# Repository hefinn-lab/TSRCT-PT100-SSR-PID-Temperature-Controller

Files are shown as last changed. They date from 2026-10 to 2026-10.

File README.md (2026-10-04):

# An Open-Source Dual-Channel RTD Thermal-Control Platform for Research-Scale PEM Water Electrolysis Balance-of-Plant Integration

The **Thermal Stability Regulatory Control Tool** **(TSRCT-PCB-01)** is an Arduino Nano Every–based temperature-control board for experimental thermal management. It connects two Pt100 or Pt1000 resistance temperature detectors (RTDs) to independent **5 V digital solid-state-relay (SSR) control outputs**, with controller power and host communication through a single USB connection. External SSRs switch a separately powered heater circuit.

**Repository release: v1.1.1 | Firmware and Python tools: V1.1**

[Setup and dependencies](DEPENDENCIES.md) • [Release notes](RELEASE-NOTES.md) • [Citation](CITATION.cff) • [Licensing](LICENSE.md)

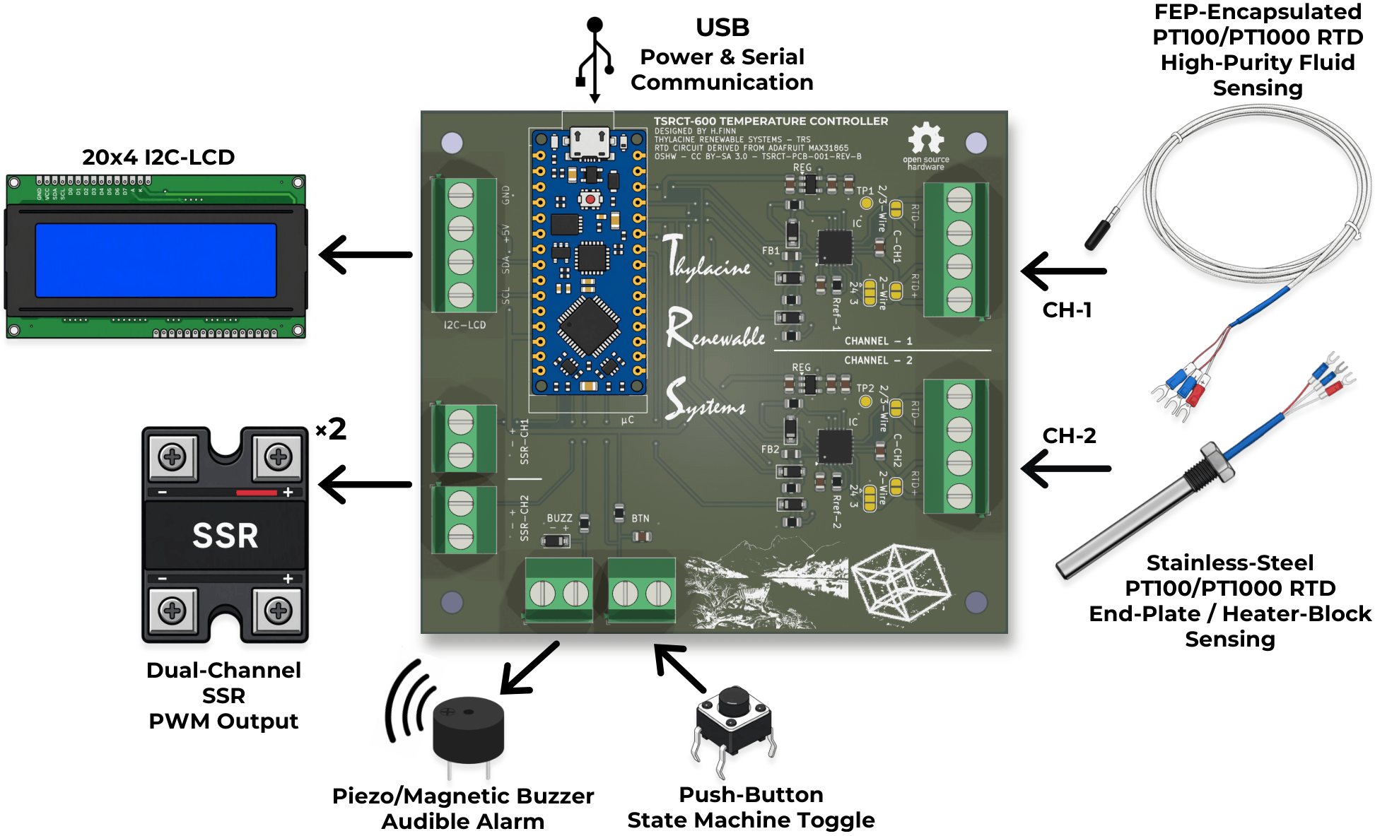
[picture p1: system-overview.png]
TSRCT-PCB-01 system overview showing dual RTD inputs, SSR outputs, USB communication and user-interface connections


The accompanying manuscript describes the circuit, analytical tuning methods, experimental results, and operating scope. The reported experiments characterise temperature control on isolated, dry electrolysis-cell end plates.

## Ordering assembled boards

Assembled boards (PCB fabrication, component sourcing, and assembly) can be ordered through PCBWay. Choose the listing that matches your sensors:

[Pt100 version](https://www.pcbway.com/project/shareproject/TSRCT_PT100_SSR_PID_Temperature_Controller_67959e58.html) | [Pt1000 version](https://www.pcbway.com/project/shareproject/TSRCT_PT1000_SSR_PID_Temperature_Controller_ba38c86e.html) | [Pt100/Pt1000 hybrid version](https://www.pcbway.com/project/shareproject/TSRCT_PT100_PT1000_SSR_PID_Temperature_Controller_0d5c73a0.html)

All three use the same PCB -- only the reference resistors and RTD input-filter capacitors differ. To use another manufacturer, the Gerber and drill files, plus a BOM and position file for each variant, are in [`Hardware/TSRCT-PCB-01-Manufacturing-Files`](Hardware/TSRCT-PCB-01-Manufacturing-Files/).

The hybrid Pt100/Pt1000 version configures channel 1 as Pt100, and channel 2 as Pt1000.

Assembled boards arrive configured for 4-wire RTDs, with the Arduino Nano Every unprogrammed -- see [RTD wiring and soldering](#rtd-wiring-and-soldering) for 2- and 3-wire use.

Disclosure: the author receives a 10% donation from PCBWay on orders placed through these listings.

## Basic functions

- Two MAX31865 RTD acquisition channels with independent temperature set points.
- Pt100 or Pt1000 operation, with matching component population and firmware settings; configurable 2-, 3-, or 4-wire connections.
- PI/PID control, manual operation, set-point ramping, and anti-windup.
- Windowed SSR actuation, with nominal 1 s control and actuation windows.
- Open-loop step-response acquisition and FOPDT-based analytical SIMC PI / iSIMC PID tuning tools.
- USB serial telemetry and companion Python logging and analysis.
- RTD fault handling, stale-measurement detection, and over-temperature alarms that disable both heater commands.
- Connections for an I²C display, push button, and audible alarm.

## Adafruit design attribution and changes

**The RTD front ends are based on the Adafruit MAX31865 breakout design by Limor Fried/Ladyada for Adafruit Industries.** The MAX31865 interface software is derived from Adafruit's Arduino library. The original projects are:

- [Adafruit MAX31865 hardware: schematics and PCB files](https://github.com/adafruit/Adafruit-MAX31865-PCB)
- [Adafruit MAX31865 Arduino library](https://github.com/adafruit/Adafruit_MAX31865)

**Hardware changes:** TSRCT-PCB-01 integrates two RTD front ends into one control PCB with the Nano Every, SSR command connections, and display, button, and alarm interfaces. The layout consolidates the measurement and control wiring while retaining configurable RTD connections. Reference resistors and input-filter capacitors are populated for the selected sensor type.

**Firmware changes:** RTD acquisition has been changed to a **non-blocking state machine**. Bias settling, conversion waiting, and readout are scheduled as separate stages so acquisition does not hold up the main loop during the sensor waiting periods. The application adds independent control loops, timer-scheduled SSR windows, analytical tuning support, fault handling, and host telemetry. The V1.1 timer implementation uses the Nano Every's ATmega4809 TCB2 peripheral; another microcontroller requires timer adaptation.

## RTD wiring and soldering

Use the Adafruit learning guide for the underlying RTD connection principles and solder-jumper configuration:

- [MAX31865 guide: overview](https://learn.adafruit.com/adafruit-max31865-rtd-pt100-amplifier/)
- [Assembly and soldering guide](https://learn.adafruit.com/adafruit-max31865-rtd-pt100-amplifier/assembly)
- [RTD wiring and configuration: 2-, 3-, and 4-wire sensors](https://learn.adafruit.com/adafruit-max31865-rtd-pt100-amplifier/rtd-wiring-config)

These instructions illustrate the Adafruit breakout. Use the **TSRCT-PCB-01 schematic and PCB labels** to identify the corresponding terminals and jumpers before soldering or cutting a trace.

| Sensor | Nominal resistance at 0 °C | Reference resistor | RTD input-filter capacitor |
| --- | ---: | ---: | ---: |
| Pt100 | 100 Ω | 430 Ω | 100 nF |
| Pt1000 | 1000 Ω | 4.3 kΩ | 10 nF |

Set the firmware's nominal RTD resistance, reference-resistor value, and wiring mode to match each populated channel. Changing from Pt100 to Pt1000 requires matching hardware and software configuration. The V1.1 default configuration uses two three-wire Pt100 sensors with 430 Ω reference resistors.

## Getting started

1. Assemble the board using its schematic and bill of materials, or order an assembled board (see above). Then make the solder jumpers and the firmware wiring mode agree with your sensors: the board's jumpers default to 4-wire, while the V1.1 firmware defaults to 3-wire. For 3-wire sensors, set the jumpers as described above; for 4-wire sensors, change `RTD_WIRE_COUNT` in the sketch.
2. Follow [DEPENDENCIES.md](DEPENDENCIES.md) to configure the Arduino Nano Every target and Arduino megaAVR Boards core, install the Python packages, and select the matching sketch/logger pair.
3. Connect the RTDs and compatible SSR control inputs, checking input-current requirements against the board's output capability. Heater power must pass through the external switching circuit, with independent thermal protection.
4. Upload the nominal-control or analytical-tuning sketch and run its companion Python logger. Before enabling heater power, confirm plausible temperature readings, correct sensor-to-heater channel pairing, and heater-off behaviour on your assembled system.

The loggers record telemetry; closing a logger does not stop heating. Use the controller's local control/abort function. Repository documentation can receive a new release version while unchanged firmware and Python tools retain V1.1.

## Attribution and licensing

Hardware design files are licensed under **CC BY-SA 3.0**. Original TSRCT software contributions are licensed under **MIT**, and Adafruit-derived code retains its upstream notices. See [LICENSE.md](LICENSE.md) for the component-specific terms and [ADAFRUIT-NOTICES.md](ADAFRUIT-NOTICES.md) for attribution. Preserve the applicable notices when redistributing or modifying the design or software.

Please acknowledge the original Adafruit projects when reusing these RTD front ends or their interface code, and refer to the accompanying manuscript for the TSRCT-PCB-01 design and experimental methods.

## Contact

Technical questions and bug reports: please open a [GitHub issue](https://github.com/hefinn-lab/TSRCT-PT100-SSR-PID-Temperature-Controller/issues). Other enquiries: Hamish Emmerson Finn, University of Tasmania, hamish.finn@utas.edu.au ([ORCID](https://orcid.org/0009-0000-0281-6255)).

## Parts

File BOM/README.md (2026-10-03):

# Reference BOM

`BOM.xlsx` is the reference bill of materials for TSRCT-PCB-01. It is intended for manual ordering and assembly: it lists Digi-Key part numbers and can be uploaded to Digi-Key's BOM tool. Quantities are for one board. The red rows are the sensor-dependent parts; order the reference resistors and channel capacitors that match each channel's sensor type (Pt100 or Pt1000).

For automated assembly (PCBA), use the files in [`Hardware/TSRCT-PCB-01-Manufacturing-Files`](../Hardware/TSRCT-PCB-01-Manufacturing-Files/) instead. That folder holds a separate BOM and position file for each population (Pt100, Pt1000, and Pt100/Pt1000), formatted for assembler upload, together with the Gerber and drill files.

Both use the same reference designators as the schematic and PCB.

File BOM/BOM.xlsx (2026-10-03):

Qty | Digi-Key Part Number | Manufacturer Part Number | Manufacturer | Customer Reference | Designation | Footprint | Notes
1 |  | ABX00033 | Arduino | uC1 | Arduino Nano Every | Module:Arduino_Nano | Nano Every (ATmega4809) required by the firmware. Same footprint as the classic Nano, which is not supported.
2 | MAX31865ATP+-ND | MAX31865ATP+ | Analog Devices | IC1, IC2 | MAX31865 | Package_DFN_QFN:TQFN-20-1EP_5x5mm_P0.65mm_EP3.1x3.1mm_ThermalVias | TQFN-20 5x5mm -- verified
2 | 576-2980-1-ND | MIC5225-3.3YM5-TR | Microchip | REG1, REG2 | MIC5225-3.3 | Package_TO_SOT_SMD:SOT-23-5 | SOT-23-5 -- verified
7 | 31-1N4148W-7-F-WCT-ND | 1N4148W-7-F-W | Diodes Inc. | D1–D7 | 1N4148 | Diode_SMD:D_SOD-123 | SOD-123 verified (NOT SOD-323). -W variant in stock
2 | 490-1054-1-ND | BLM21PG221SN1D | Murata | FB1, FB2 | Ferrite 220Ω @ 100MHz | Inductor_SMD:L_0805_2012Metric | 0805 verified
VAR. | P430DACT-ND | ERA-6AEB431V | Panasonic | Rref-1, Rref-2 (Pt100 channels) | 430Ω 0.1% thin-film | Resistor_SMD:R_0805_2012Metric | 0805 verified - Rref for PT100 channels. Populate one per PT100 channel
VAR. | P4.3KDACT-ND | ERA-6AEB432V | Panasonic | Rref-1, Rref-2 (Pt1000 channels) | 4.3kΩ 0.1% thin-film | Resistor_SMD:R_0805_2012Metric | 0805 verified - Rref for Pt1000 channels. Populate one per PT1000 channel
7 | 311-10.0KCRCT-ND | RC0805FR-0710KL | Yageo | R2, R3, R4, R6, R7, R8, R9 | 10K 1% | Resistor_SMD:R_0805_2012Metric | 0805 verified
1 | 311-220CRCT-ND | RC0805FR-07220RL | Yageo | R10 | 220Ω 1% | Resistor_SMD:R_0805_2012Metric | 0805 verified
4 | 1276-1003-1-ND | CL21B104KBCNNNC | Samsung | C1, C2, C8, C9 | 0.1uF X7R 50V | Capacitor_SMD:C_0805_2012Metric | 0805 verified. Decoupling.
VAR. | 1276-1003-1-ND | CL21B104KBCNNNC | Samsung | C-CH1, C-CH2 (Pt100 channels) | 0.1uF X7R 50V | Capacitor_SMD:C_0805_2012Metric | PT100 channel filter. Placed as C-CH1/C-CH2. Populate one per PT100 channel
4 | 1276-6454-1-ND | CL21A106KAYNNNG | Samsung | C4, C5, C11, C13 | 10uF X5R 25V | Capacitor_SMD:C_0805_2012Metric | 0805 verified. G-variant of original E-variant (out of stock); identical electrical spec.
1 | 1276-1029-1-ND | CL21B105KBFNNNE | Samsung | C6 | 1uF X7R 50V | Capacitor_SMD:C_0805_2012Metric | 0805 verified. Button debounce.
VAR. | 1276-1015-1-ND | CL21B103KBANNNC | Samsung | C-CH1, C-CH2 (Pt1000 channels) | 10nF X7R 50V | Capacitor_SMD:C_0805_2012Metric | PT1000 channel filter. Placed as C-CH1/C-CH2. Populate one per PT1000 channel
3 | 277-1265-ND | 1715747 | Phoenix Contact | J6, J7, I2C-LCD1 | Screw_Terminal_01x04 5.08mm | TerminalBlock_Phoenix:TerminalBlock_Phoenix_MKDS-1,5-4-5.08_1x04_P5.08mm_Horizontal | MKDS 1,5/4-5,08 — 4-pos 5.08mm verified
4 | 277-1263-ND | 1715721 | Phoenix Contact | SSR-CH1, SSR-CH2, BTN1, BUZZ1 | Screw_Terminal_01x02 5.08mm | TerminalBlock_Phoenix:TerminalBlock_Phoenix_MKDS-1,5-2-5.08_1x02_P5.08mm_Horizontal | MKDS 1,5/2-5,08 — 2-pos 5.08mm
 | BOM Note: All quantities are for one assembled TSRCT-PCB-001 PCB unless otherwise stated. Red rows are RTD-configuration-dependent components; populate the appropriate values for the selected PT100/PT1000 channel configuration. Reference designators match the schematic, the PCB and the assembly files in TSRCT-PCB-01-Manufacturing-Files.

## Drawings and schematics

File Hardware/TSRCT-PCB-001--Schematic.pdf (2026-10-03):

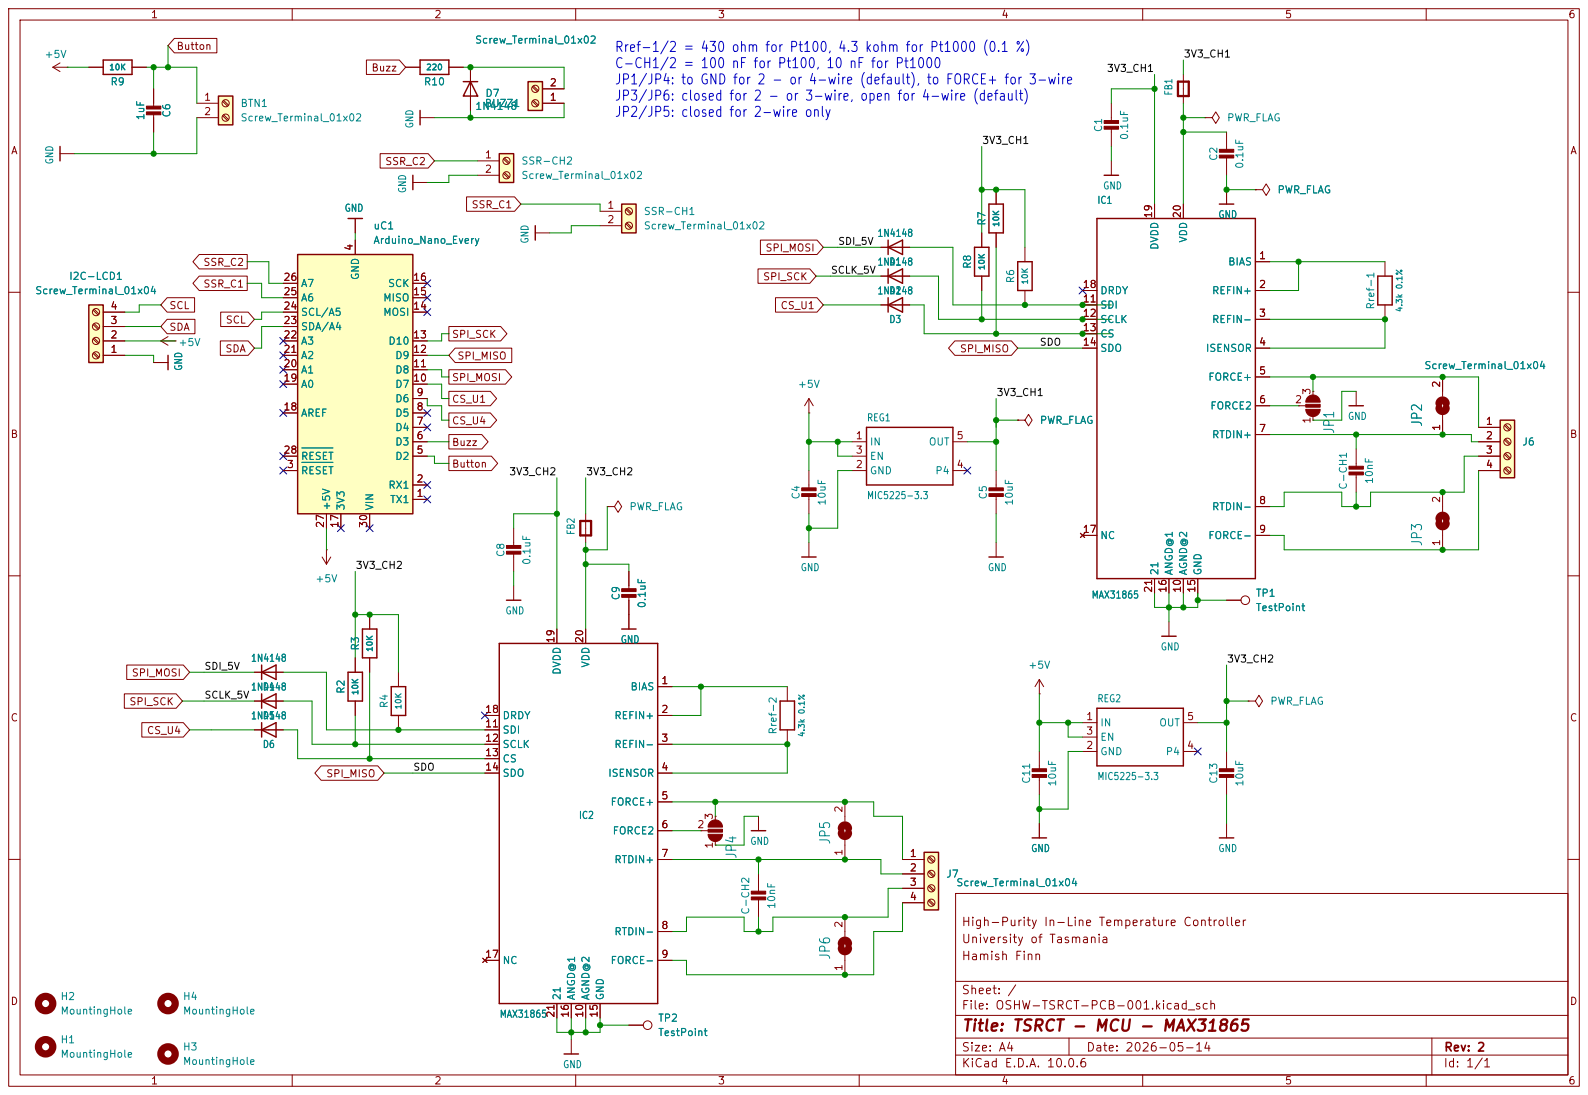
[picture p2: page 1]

C-CH1/2 = 100 nF for Pt100, 10 nF for Pt1000
JP1/JP4: to GND for 2 - or 4-wire (default), to FORCE+ for 3-wire
JP3/JP6: closed for 2 - or 3-wire, open for 4-wire (default)
JP2/JP5: closed for 2-wire only

High-Purity In-Line Temperature Controller GND GND

Sheet: /
File: OSHW-TSRCT-PCB-001.kicad_sch
Title: TSRCT - MCU - MAX31865

Size: A4 | Rev: 2
KiCad E.D.A. 10.0.6 | Id: 1/1

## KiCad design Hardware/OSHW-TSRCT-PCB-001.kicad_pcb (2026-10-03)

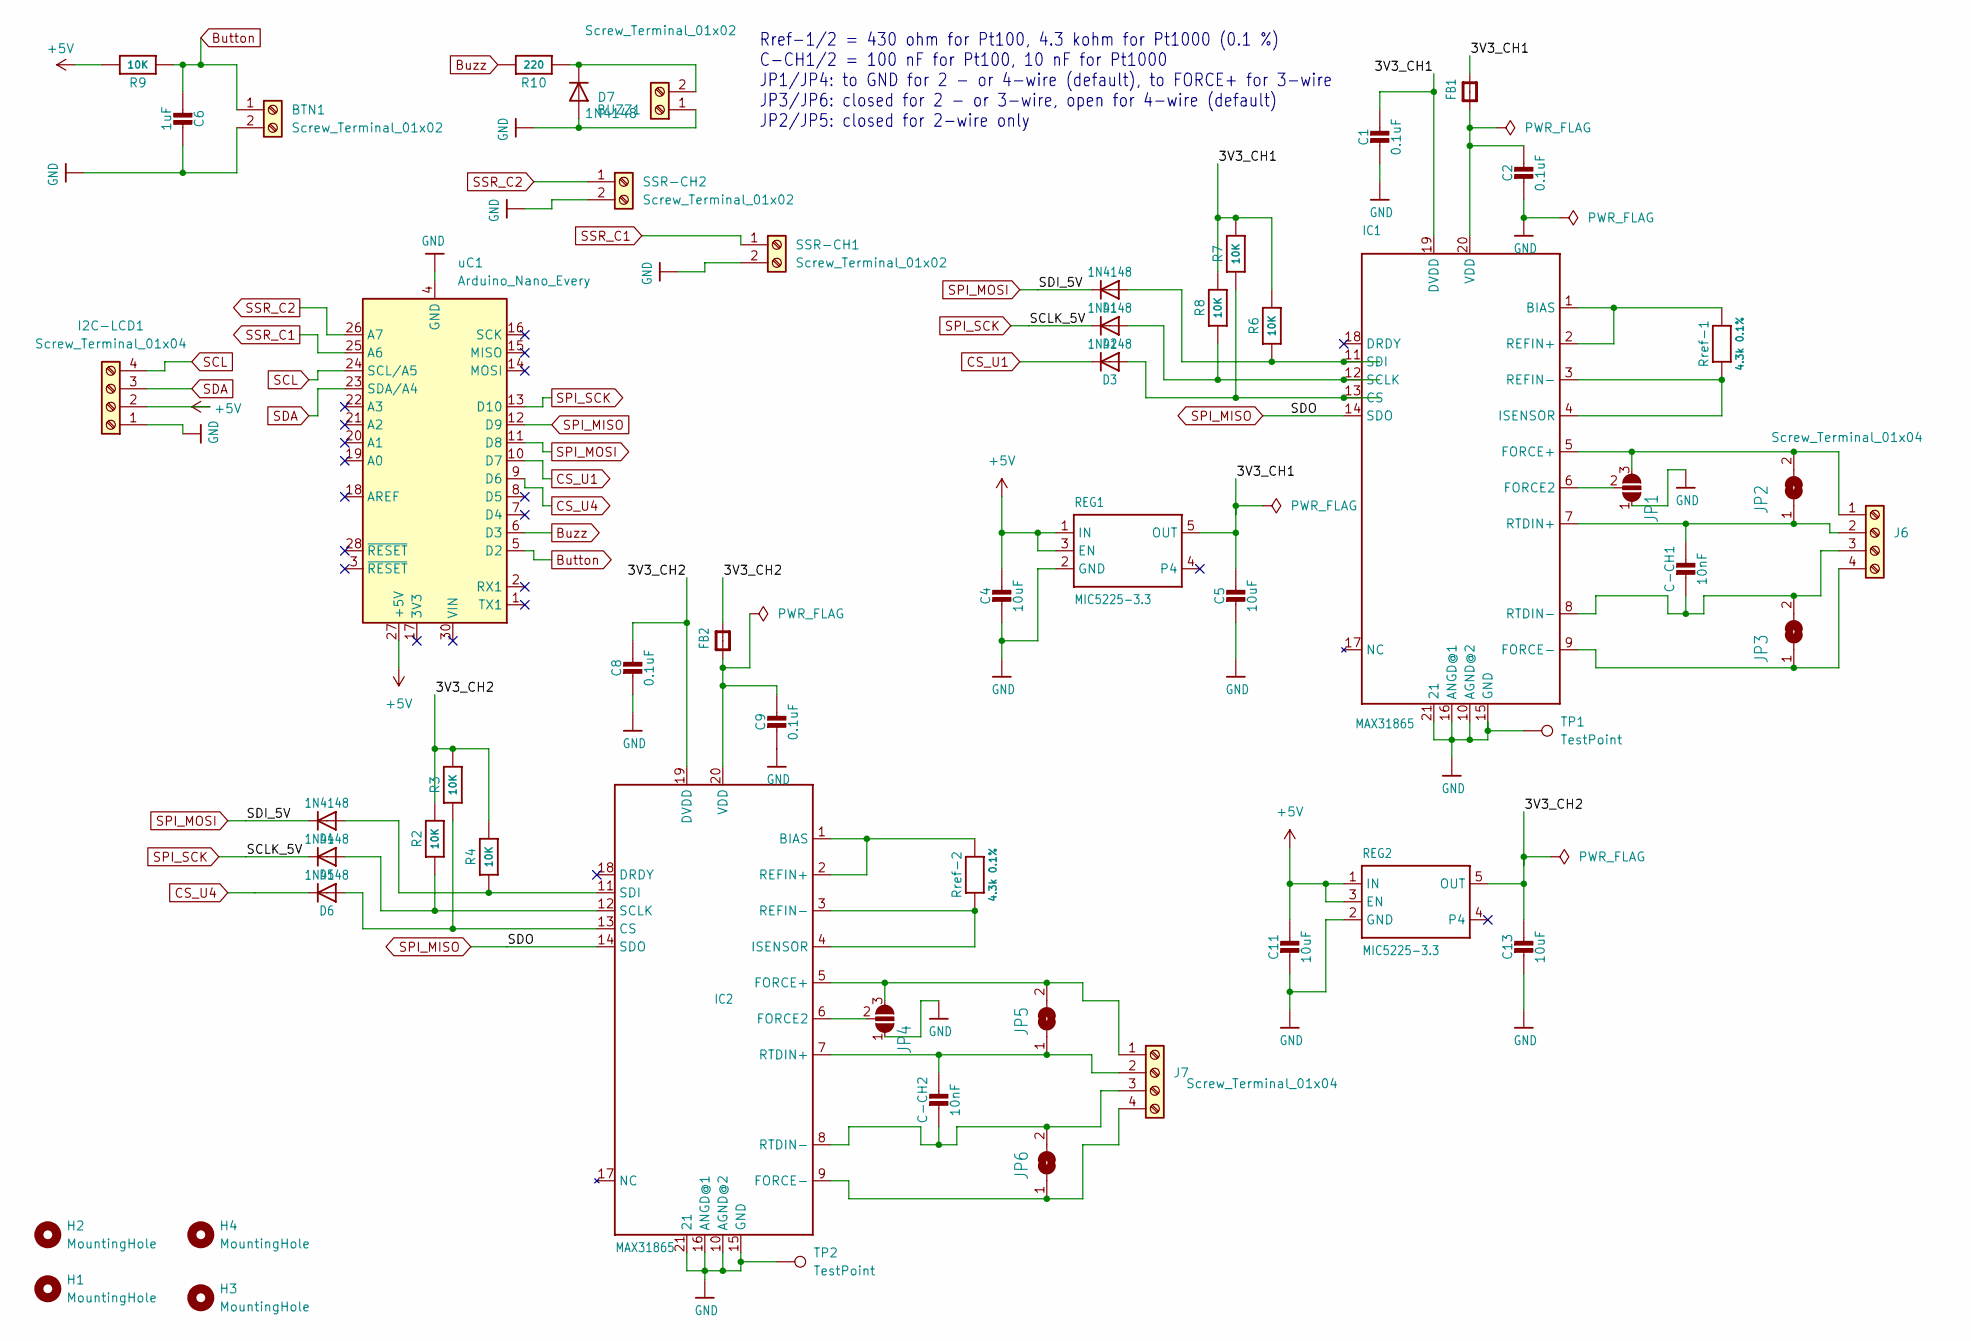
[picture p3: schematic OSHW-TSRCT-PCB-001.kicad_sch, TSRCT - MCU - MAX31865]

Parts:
BTN1: Screw_Terminal_01x02; TerminalBlock_Phoenix_MKDS-1,5-2-5.08_1x02_P5.08mm_Horizont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
BUZZ1: Screw_Terminal_01x02; TerminalBlock_Phoenix_MKDS-1,5-2-5.08_1x02_P5.08mm_Horizont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
C1, C2, C8, C9: 0.1uF; C_0805_2012Metric
C4, C5, C11, C13: 10uF; C_0805_2012Metric
C6: 1uF; C_0805_2012Metric
C-CH1, C-CH2: 10nF; C_0805_2012Metric
D1, D2, D3, D4, D5, D6, D7: 1N4148; D_SOD-123
FB1, FB2: FERRITE-0805NO; L_0805_2012Metric
H1, H2, H3, H4: MountingHole; MountingHole_3.2mm_M3
I2C-LCD1: Screw_Terminal_01x04; TerminalBlock_Phoenix_MKDS-1,5-4-5.08_1x04_P5.08mm_Horizont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
IC1, IC2: MAX31865; TQFN-20-1EP_5x5mm_P0.65mm_EP3.1x3.1mm_ThermalVias
J6, J7: Screw_Terminal_01x04; TerminalBlock_Phoenix_MKDS-1,5-4-5.08_1x04_P5.08mm_Horizont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
JP1, JP4: 24 3; SolderJumper-3_P1.3mm_Bridged12_RoundedPad1.0x1.5mm
JP2, JP5: 2-Wire; SolderJumper-2_P1.3mm_Open_RoundedPad1.0x1.5mm
JP3, JP6: 2/3-Wire; SolderJumper-2_P1.3mm_Open_RoundedPad1.0x1.5mm
R2, R3, R4, R6, R7, R8, R9: 10K; R_0805_2012Metric
R10: 220; R_0805_2012Metric
REG1, REG2: MIC5225-3.3; SOT-23-5
Rref-1, Rref-2: 4.3k 0.1%; R_0805_2012Metric
SSR-CH1, SSR-CH2: Screw_Terminal_01x02; TerminalBlock_Phoenix_MKDS-1,5-2-5.08_1x02_P5.08mm_Horizont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
TP1, TP2: TestPoint; TestPoint_Pad_D1.5mm
uC1: Arduino_Nano_Every; Arduino_Nano

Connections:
+5V: C4.1, C11.1, I2C-LCD1.2, R9.2, REG1.1 (IN), REG1.3 (EN), REG2.1 (IN), REG2.3 (EN), uC1.27 (+5V)
/3V3_CH1: C1.1, C5.1, FB1.2, IC1.19 (DVDD), R6.2, R7.2, R8.2, REG1.5 (OUT)
/3V3_CH2: C8.1, C13.1, FB2.2, IC2.19 (DVDD), R2.2, R3.2, R4.2, REG2.5 (OUT)
Button: BTN1.1, C6.2, R9.1, uC1.5 (D2)
Buzz: R10.2, uC1.6 (D3)
CS_U1: D3.1, uC1.10 (D7)
CS_U4: D6.1, uC1.9 (D6)
GND: BTN1.2, BUZZ1.1, C1.2, C2.2, C4.2, C5.2, C6.1, C8.2, C9.2, C11.2, C13.2, D7.2 (A), I2C-LCD1.1, IC1.10 (AGND@2), IC1.15 (GND), IC1.16 (ANGD@1), IC1.21, IC2.10 (AGND@2), IC2.15 (GND), IC2.16 (ANGD@1), IC2.21, JP1.1, JP4.1, REG1.2 (GND), REG2.2 (GND), SSR-CH1.2, SSR-CH2.2, TP1.1 (1_1), TP2.1 (1_1), uC1.4 (GND), uC1.29 (GND)
unnamed: BUZZ1.2, D7.1 (K), R10.1
unnamed: C2.1, FB1.1, IC1.20 (VDD)
unnamed: C9.1, FB2.1, IC2.20 (VDD)
unnamed: IC1.1 (BIAS), IC1.2 (REFIN+), Rref-1.2
unnamed: D3.2, IC1.13 (CS), R7.1
unnamed: IC1.6 (FORCE2), JP1.2
unnamed: IC1.5 (FORCE+), J6.1, JP1.3, JP2.2
unnamed: IC1.9 (FORCE-), J6.4, JP3.1
unnamed: IC1.3 (REFIN-), IC1.4 (ISENSOR), Rref-1.1
unnamed: C-CH1.1, IC1.7 (RTDIN+), J6.2, JP2.1
unnamed: C-CH1.2, IC1.8 (RTDIN-), J6.3, JP3.2
unnamed: D2.2, IC1.12 (SCLK), R8.1
unnamed: D1.2, IC1.11 (SDI), R6.1
unnamed: IC2.1 (BIAS), IC2.2 (REFIN+), Rref-2.2
unnamed: D6.2, IC2.13 (CS), R3.1
unnamed: IC2.6 (FORCE2), JP4.2
unnamed: IC2.5 (FORCE+), J7.1, JP4.3, JP5.2
unnamed: IC2.9 (FORCE-), J7.4, JP6.1
unnamed: IC2.3 (REFIN-), IC2.4 (ISENSOR), Rref-2.1
unnamed: C-CH2.1, IC2.7 (RTDIN+), J7.2, JP5.1
unnamed: C-CH2.2, IC2.8 (RTDIN-), J7.3, JP6.2
unnamed: D5.2, IC2.12 (SCLK), R2.1
unnamed: D4.2, IC2.11 (SDI), R4.1
SCL: I2C-LCD1.4, uC1.24 (SCL/A5)
SDA: I2C-LCD1.3, uC1.23 (SDA/A4)
SPI_MISO: IC1.14 (SDO), IC2.14 (SDO), uC1.12 (D9)
SPI_MOSI: D1.1, D4.1, uC1.11 (D8)
SPI_SCK: D2.1, D5.1, uC1.13 (D10)
SSR_C1: SSR-CH1.1, uC1.25 (A6)
SSR_C2: SSR-CH2.1, uC1.26 (A7)

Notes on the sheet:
Rref-1/2 = 430 ohm for Pt100, 4.3 kohm for Pt1000 (0.1 %) C-CH1/2 = 100 nF for Pt100, 10 nF for Pt1000 JP1/JP4: to GND for 2 - or 4-wire (default), to FORCE+ for 3-wire JP3/JP6: closed for 2 - or 3-wire, open for 4-wire (default) JP2/JP5: closed for 2-wire only

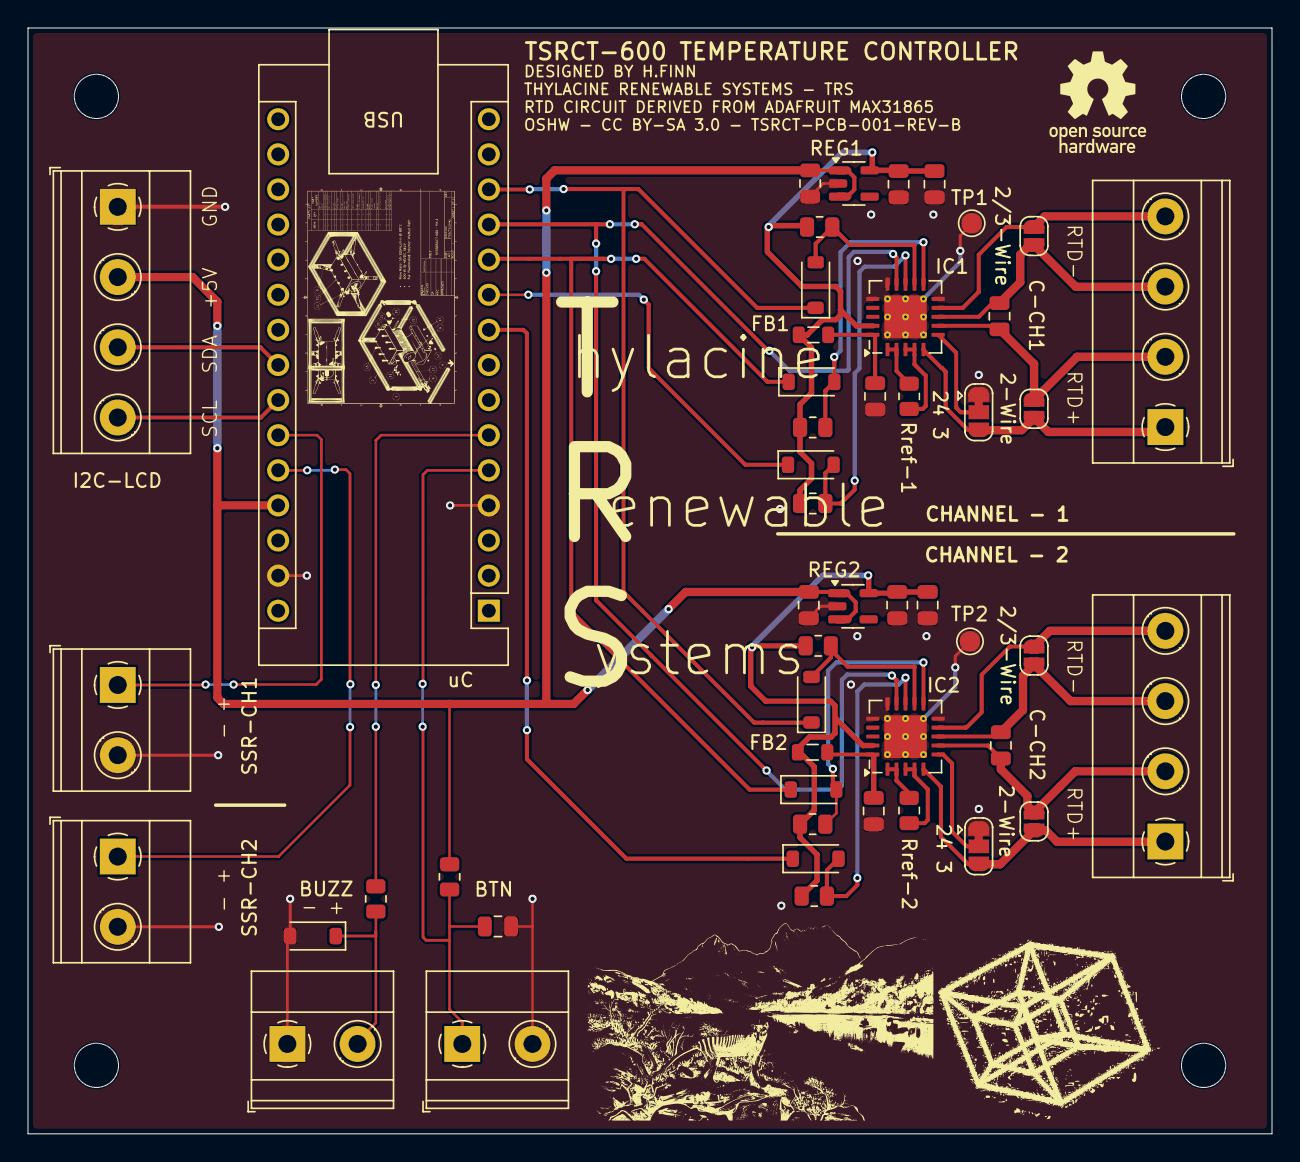
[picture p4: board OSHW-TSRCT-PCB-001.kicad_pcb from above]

Board: 2 copper layers, 90.0 x 80.0 mm, 54 parts (0 on the bottom side), 38 nets.

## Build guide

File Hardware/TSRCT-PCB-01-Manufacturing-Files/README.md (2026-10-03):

# TSRCT-PCB-01 manufacturing files

Files for PCB fabrication and assembly (PCBA) of TSRCT-PCB-01.

| Item | Contents |
|---|---|
| `Gerber_Drill.zip` | Gerber and drill files, common to all variants (KiCad 10.0.6, 2 layers, 1.6 mm, 90 x 80 mm) |
| `Pt100-Manufacture-Files/` | BOM and position (centroid) file, both channels populated for Pt100 |
| `Pt1000-Manufacture-Files/` | BOM and position (centroid) file, both channels populated for Pt1000 |
| `Pt100-Pt1000-Hybrid-Manufacture-Files/` | BOM and position (centroid) file, channel 1 Pt100, channel 2 Pt1000 |

The three variants use the same PCB and the same component positions. Only four parts differ:

| Variant | Rref-1 | Rref-2 | C-CH1 | C-CH2 |
|---|---|---|---|---|
| Pt100 | 430 ohm 0.1 % (ERA-6AEB431V) | 430 ohm 0.1 % (ERA-6AEB431V) | 100 nF (CL21B104KBCNNNC) | 100 nF (CL21B104KBCNNNC) |
| Pt1000 | 4.3 kohm 0.1 % (ERA-6AEB432V) | 4.3 kohm 0.1 % (ERA-6AEB432V) | 10 nF (CL21B103KBANNNC) | 10 nF (CL21B103KBANNNC) |
| Hybrid | 430 ohm 0.1 % (ERA-6AEB431V) | 4.3 kohm 0.1 % (ERA-6AEB432V) | 100 nF (CL21B104KBCNNNC) | 10 nF (CL21B103KBANNNC) |

Each BOM lists 42 placements, and its Ref, Val and Package columns match the position file in the same folder.

The RTD wire-configuration solder jumpers (JP1 to JP6), test points (TP1, TP2) and mounting holes (H1 to H4) are not BOM parts and are not in the position files. Assembled boards are ready for 4-wire RTD operation with no soldering required. For 2-wire or 3-wire sensors, the solder jumpers beside each MAX31865 are set by hand after assembly; see the repository README.

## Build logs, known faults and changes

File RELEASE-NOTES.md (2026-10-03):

# TSRCT-PCB-01 v1.1.1

Public release of TSRCT-PCB-01, an open-source dual-channel Pt100/Pt1000 PID temperature-control platform for Arduino Nano Every, developed for research-scale PEM water electrolysis thermal management.

Repository release **v1.1.1** packages firmware and companion Python tools **V1.1**.

This release brings together:

- Hardware design and fabrication files, bill of materials, and assembly documentation.
- Dual-channel nominal-control firmware with non-blocking MAX31865 acquisition, 5 V SSR commands, PI/PID control, and fault handling.
- Open-loop step-identification firmware and Python tools for FOPDT identification and SIMC PI / iSIMC PID tuning.
- Python serial logging with CSV and XLSX output.
- Dependency instructions, citation metadata, and component-specific licensing and Adafruit attribution.

The RTD front ends are adapted from Adafruit's MAX31865 hardware design. The incorporated Adafruit-derived interface code has been restructured for non-blocking acquisition.

Hardware: CC BY-SA 3.0. Original software: MIT. Adafruit-derived software retains its upstream BSD notice; see [LICENSE.md](LICENSE.md) and [ADAFRUIT-NOTICES.md](ADAFRUIT-NOTICES.md).

See [DEPENDENCIES.md](DEPENDENCIES.md) for the supported board, matched firmware/logger pairs, and setup. The accompanying manuscript describes the experimental performance on isolated, dry end plates. Before enabling heating, adopters should confirm operation on their assembled hardware using the checks in the [README](README.md).

## Update, 3 October 2026 (v1.1.1; hardware, firmware and Python tools unchanged)

- Reference designators made unique for automated assembly: IC1/IC2, REG1/REG2, uC1, BTN1, BUZZ1, I2C-LCD1, and JP1–JP6 for the RTD solder jumpers. The schematic, PCB, schematic PDF and BOM are updated to match. The silkscreen keeps the functional labels.
- Added [`Hardware/TSRCT-PCB-01-Manufacturing-Files`](Hardware/TSRCT-PCB-01-Manufacturing-Files/): Gerber and drill files, plus a BOM and position file for each of the Pt100, Pt1000 and Pt100/Pt1000 configurations.
- MAX31865 SDO pin type corrected to tri-state in the schematic symbol. This clears an ERC error and is not a circuit change.
- Copper, solder mask, paste, board outline and drill data are unchanged.
- README: added ordering links for assembled boards (PCBWay), with a commission disclosure, and contact details.
- Microcontroller value corrected to Arduino_Nano_Every in the schematic, BOM and position files -- footprint was correct and is unchanged.
- Known issue: DRC reports a thermal-relief spoke-count warning at the MAX31865 exposed-pad vias and at one pull-up resistor pad. It has no electrical or thermal effect at this board's power level (IC dissipation of tens of mW, pull-up current 0.5 mA) and is left as is so the released copper matches the tested boards.

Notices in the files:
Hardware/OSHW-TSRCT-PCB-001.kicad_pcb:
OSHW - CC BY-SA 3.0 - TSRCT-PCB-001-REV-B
